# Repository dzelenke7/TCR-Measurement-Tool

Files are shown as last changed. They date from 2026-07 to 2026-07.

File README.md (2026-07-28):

# TCR-Measurement-Tool

## Overview
This project is a Temperature Coefficient of Resistance (TCR) measurement 
tool built around two voltage divider circuits, a NTC thermistor, and an 
Arduino Uno R3. The system simultaneously measures the resistance of a test 
resistor and the surrounding temperature in real time, logging both over 
serial to a Python data pipeline that plots resistance vs temperature and 
extracts TCR via linear regression.

Accurate TCR characterization is directly relevant to semiconductor 
engineering. Process engineers at fabrication facilities routinely measure 
how thin film resistors and other on-chip components behave under thermal 
stress. This project simulates that at a basic level.

## Theory
### Temperature Coefficient of Resistance (TCR)
TCR describes how a resistor's resistance changes per degree of temperature 
change, expressed in ppm/°C:

TCR = (R(T) - R(T₀)) / (R(T₀) · (T - T₀)) × 10⁶

In practice, TCR is extracted by fitting a line to measured R vs T data. 
The slope of that line (dR/dT) divided by the initial resistance R₀ gives 
TCR directly:

TCR = (slope / R₀) × 10⁶

### Resistance from Voltage Divider
The Arduino reads a raw ADC value (0-1023) and converts it to voltage:

V_out = ADC × (5.0 / 1023.0)

The test resistor sits at the bottom of the voltage divider, so resistance 
is back-calculated as:

R_test = (V_out × R_ref) / (5.0 - V_out)

### Temperature from Thermistor; Beta Equation
The thermistor resistance is measured using an identical voltage divider on 
analog pin A1. Temperature is then calculated using the Beta equation:

T = B / (ln(R_therm / R₀) + B / 298.0) - 273.0

Where B = 3950 (Beta constant), R₀ = 10,000Ω (thermistor resistance at 
25°C), and T is in Celsius. Beta constants were sourced from published NTC 
10K thermistor specifications.
## Hardware
 - Arduino Uno R3
 - 2 33kΩ Resistors (voltage divider references for test resistor and thermistor circuits)
 - 1 test Resistor (33kΩ carbon film used in this project, but any resistor can be tested)
 - NTC 10K Thermistor (Should be in contact with Test Resistor)
 - 10K Potentiometer (LCD contrast adjustment)
 - 1k Resistor (LCD backlight current limiter)
 - QAPASS 16x2 LCD Display
 - Breadboard and Jumper wires
 - Heat source (Hair Dryer recommended for 40°C+ temperature range)
   
## Software
### Arduino Sketch
Reads raw ADC values from two analog pins and uses the voltage divider 
equation to back-calculate the resistance of the test resistor and the 
thermistor. Converts thermistor resistance to temperature using the Beta 
equation, outputting both Celsius and Fahrenheit. Displays live temperature 
and resistance readings on the 16x2 LCD and transmits tempC, R_test, and 
R_therm over serial at 9600 baud every 200ms.

### Python Script
Establishes a serial connection with the Arduino and continuously reads 
tempC, R_test, and R_therm into three lists until interrupted with Ctrl+C. 
Upon termination, fits a linear regression to the R_test vs tempC data using 
numpy, extracts TCR from the slope, prints the result, and plots resistance 
vs temperature with the measured data points and fitted line overlaid.

**Libraries used:**
- pyserial --> serial communication with Arduino
- matplotlib --> data plotting
- numpy --> linear regression and array operations
- time --> serial connection delay on startup

**Arduino Libraries:**
- LiquidCrystal.h --> LCD display control

## Results
### Test on 33kΩ Resistor
For my first test I used my fingers to generate the heat. This created a temperature range of ~24°C - 40°C.

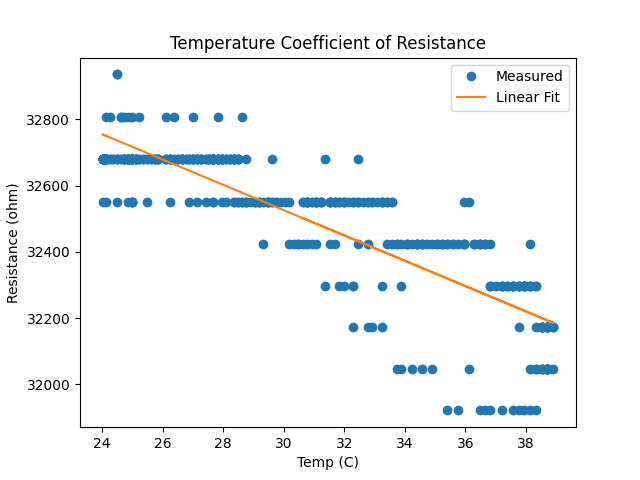
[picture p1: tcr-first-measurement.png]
Fingers Heat Source


For my second test I used a Hair Dryer to generate the heat. This created a temperature range of ~24°C - 67°C.

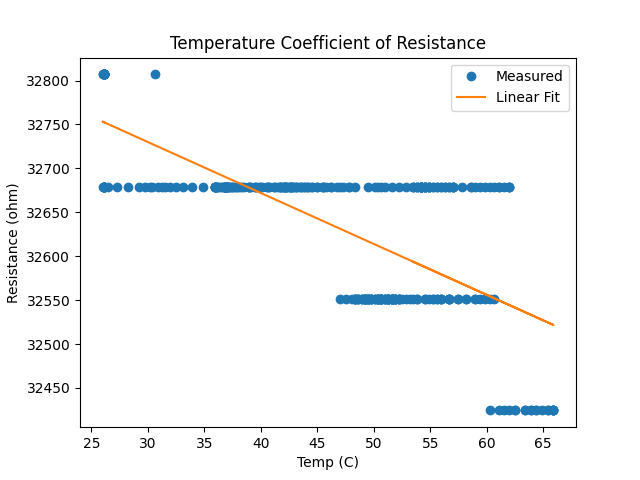
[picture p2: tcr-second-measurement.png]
Hair Dryer Heat Source

   TCR = -176.9 ppm/C

A negative TCR is characteristic of carbon film resistors, where increased 
thermal energy reduces carrier mobility and therefore resistance. This finding 
is notable because the resistors used were listed as "metal film" in their 
product specifications. Metal film resistors typically exhibit a positive or 
near-zero TCR of ±15 to ±100 ppm/°C. The measured -176.9 ppm/°C suggests 
the product specification is inaccurate, a finding that demonstrates the 
value of real, measured characterization over datasheet trust. 

The resistance data shows discrete horizontal banding rather than a smooth 
continuous curve, which is a direct consequence of the Arduino Uno's 10-bit 
ADC resolution. Each ADC step represents approximately 4.9mV, which at the 
operating resistance range translates to roughly 150Ω per step, larger than 
the per-degree resistance change expected from TCR. Despite this quantization 
limit, the downward trend across bands is consistent and the linear fit 
captures the underlying TCR behavior accurately.
## How to Run
### Arduino Wiring
- Analog 0: Between R_ref1 and R_test
- Analog 1: Between R_ref2 and R_therm
- Digital 4: RS (LCD)
- Digital 6: E (LCD)
- Digital 10: D4 (LCD)
- Digital 11: D5 (LCD)
- Digital 12: D6 (LCD)
- Digital 13: D7 (LCD)

### Resistor Divider
- 5V: Top of R_ref1 and R_ref2
- GND: Bottom of R_test and R_therm
- A0: Junction of R_ref1 and R_test
- A1: Junction of R_ref2 and R_therm

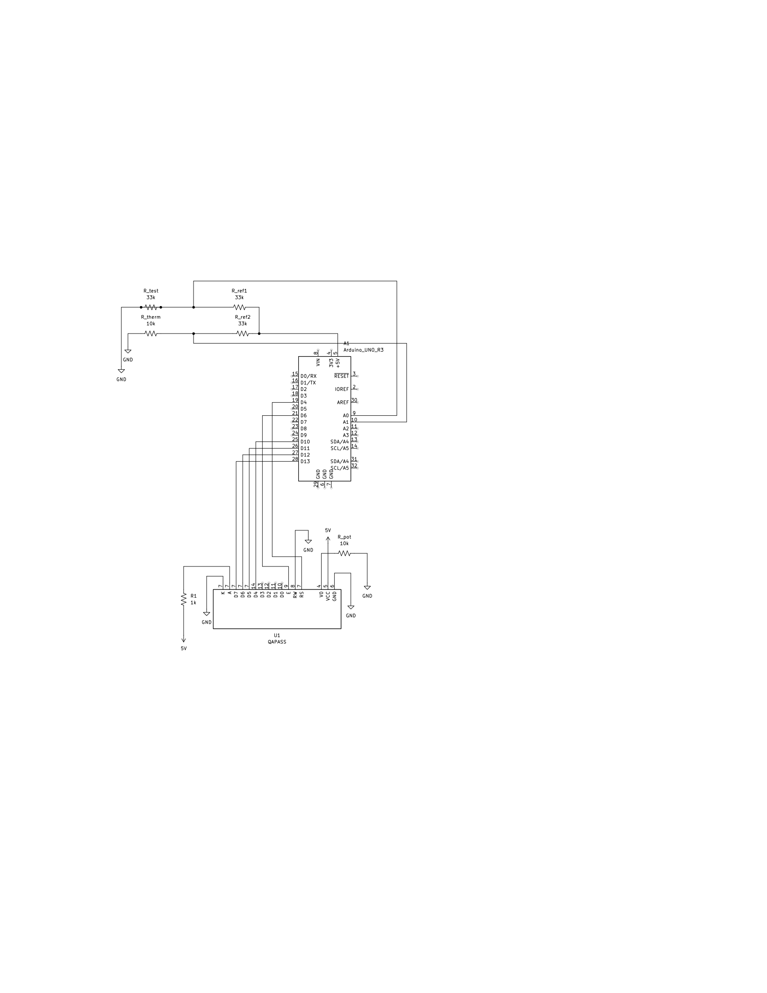
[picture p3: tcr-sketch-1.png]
tcr-sketch


### Running the Project

1.**Upload the Arduino sketch:** Open `tcr-arduino-sketch.ino` in the Arduino 
  IDE, select your board (Arduino Uno) and COM port under Tools, then click 
  Upload. The Arduino will begin measuring raw ADC values and printing Temperature in C, Test Resistance, Thermistor Resistance. 

2. **Run the Python script:** Close the Arduino Serial Monitor (it locks the 
   COM port), then run `TCR_measurement_tool.py` from a terminal (I used IDLE) in the 
   project folder. Update the COM port in the script if it differs from 
   your COM. The script will read live data from the Arduino and print it to the 
   terminal in real time.

3. **Expected output:** When running correctly, the live serial script 
   prints a Temperature in C, Test Resistance, and Thermistor Resistance,
   reading every 200ms. Python then produces a graph with either a positive
   slope/TCR (metal film resistors) or negative slope/TCR (carbon film resistors)

4. **TCR Result:** Upon Ctrl+C the script prints the calculated TCR value 
   in ppm/°C to the terminal. A negative value indicates carbon film 
   behavior, a positive value indicates metal film behavior.

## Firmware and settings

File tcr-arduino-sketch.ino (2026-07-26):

#include <LiquidCrystal.h>
                                                
LiquidCrystal lcd(4, 6, 10, 11, 12, 13);

#define div2  1                                   // the thermistor attach to 
#define div1 0                                    // reference resistor
#define R_ref1 33000                              
#define R_ref2 33000
const int B = 3950;                               // the beta of the thermistor
const float R0 = 10000.0;                         // starting resistance

void setup()
{
  Serial.begin(9600);
  pinMode(div1, INPUT);                           // to read voltage at the voltage divider of the test resistor
  pinMode(div2, INPUT);                           // to read voltage at the voltage divider of the thermistor

  // set up the LCD's number of columns and rows:
  lcd.begin(16, 2);
  lcd.clear();
}

void loop()
{
  // read thermistor value
  long a = analogRead(div2);

  float V_therm = a * (5.0 / 1023.0);                       

  float V_out = analogRead(div1) * (5.0 / 1023.0);
  
  float R_test = (V_out * R_ref1) / (5.0 - V_out);

  float R_therm = (R_ref2 * V_therm) / (5.0 - V_therm);

  float tempC = B / (log(R_therm / R0) + B / 298.0) - 273.0;
  float tempF = 1.8 * tempC + 32.0;



  lcd.setCursor(0, 0);                                 // set the cursor to column 0, line 0
  lcd.print("Temp: ");                                 // Print a message of "Temp: "to the LCD.
                                                       // Print temp in Fahrenheit
  lcd.print(tempF);
                                                      
  lcd.print(char(223));                                // print the degree symbol
  lcd.print("F");
                                                      
  lcd.setCursor(0, 1);                                 // set the cursor to column 0, line 1
  lcd.print("R_test:");                                
  lcd.print(R_test);                                   // print the test resistors resistance to the LCD.

  // Send data to py.
  Serial.println(tempC);
  Serial.println(R_test);
  Serial.println(R_therm);

  delay(200);                                          //wait for 100 milliseconds
}

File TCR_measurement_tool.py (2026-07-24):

import serial
import matplotlib.pyplot as plt
import time
import numpy as np

ser = serial.Serial('COM5', 9600)
time.sleep(2)

temp_c = []
r_test = []
r_therm = []

print('Reading data... press Ctrl+C to stop and plot')

while True:
    try:
        line1 = ser.readline().decode('utf-8').strip()
        line2 = ser.readline().decode('utf-8').strip()
        line3 = ser.readline().decode('utf-8').strip()

        print(f"Raw: '{line1}' '{line2}' '{line3}'")

        temp_c.append(float(line1))
        r_test.append(float(line2))
        r_therm.append(float(line3))

        print(f"T: {float(line1):.1f} C | R_Test: {float(line2):2e} Ohm | T_Therm: {float(line3):.3f}")

    except KeyboardInterrupt:
        break

    except Exception as e:
        print(f"Error: {e}")
        print(f"Bad data was: '{line1}' '{line2}' '{line3}'")

print(f"Total readings collected: {len(temp_c)}")
print(temp_c)

coeffs = np.polyfit(temp_c, r_test, 1)
slope = coeffs[0]
fitted_line = np.polyval(coeffs, temp_c)
R0_measured = r_test[0]
TCR = (slope / R0_measured) * 1e6
print(f"TCR = {TCR:.1f} ppm/C")

plt.plot(temp_c, r_test, 'o', label='Measured')
plt.plot(temp_c, fitted_line, '-', label='Linear Fit')
plt.legend()
plt.title("Temperature Coefficient of Resistance")
plt.xlabel("Temp (C)")
plt.ylabel("Resistance (ohm)")
plt.show()
ser.close()
